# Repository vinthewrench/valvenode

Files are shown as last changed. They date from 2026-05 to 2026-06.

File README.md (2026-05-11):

# ValveNode

ValveNode is a wired field-bus irrigation valve-control system for my Raspberry Pi farm automation stack.

This project is a continuation of the work described in [Off-Grid Farm Automation with Raspberry Pi](https://www.vinthewrench.com/p/off-grid-farm-automation-raspberry-pi).

The irrigation side started with a Raspberry Pi, relay outputs, and conventional sprinkler valve wiring, described in [Raspberry Pi Internet of Things - part 2: Controlling the Irrigation valves](https://www.vinthewrench.com/p/raspberry-pi-internet-of-things-part-23c). That proved the basic idea: local software can control real irrigation hardware without a cloud service or proprietary controller. It also exposed the usual field problems: long wire runs, voltage drop, power loss, serviceability, and too many individual valve wires returning to one box.

I later experimented with more efficient solenoid drive hardware using a DRV103 in [Not Another Sprinkler Valve Article](https://www.vinthewrench.com/p/not-another-sprinkler-valve-article). That design gives a conventional valve a strong opening pulse and then reduces average power with PWM, which matters for long wire runs and battery-backed operation.

As the farm kept expanding, the wiring problem started to matter more than the valve-control problem. Every new irrigation zone meant another long wire run back to the controller, more trenching, more splices, more voltage drop, and more things to troubleshoot later. At that point, spending a few extra dollars per valve for latching solenoids was worth it if it let the field wiring become a simple 4-wire RS-485 network.

ValveNode takes the next step: instead of pulling every valve wire back to the controller, it moves small controller cards out into the field.

A Raspberry Pi talks to a Valve Master over I2C. The Valve Master starts a 4-wire RS-485 field cable carrying power and data. Valve Node cards sit along that cable, and each card drives a local latching irrigation solenoid with a short polarity-controlled pulse.

The goal is simple: irrigation control that is local, wired, understandable, repairable, and expandable.

## Overview

The project has two primary components:

- `valvenode-master`  
  ATmega88PB-based I2C-to-RS-485 master controller.
  
    <p align="center">
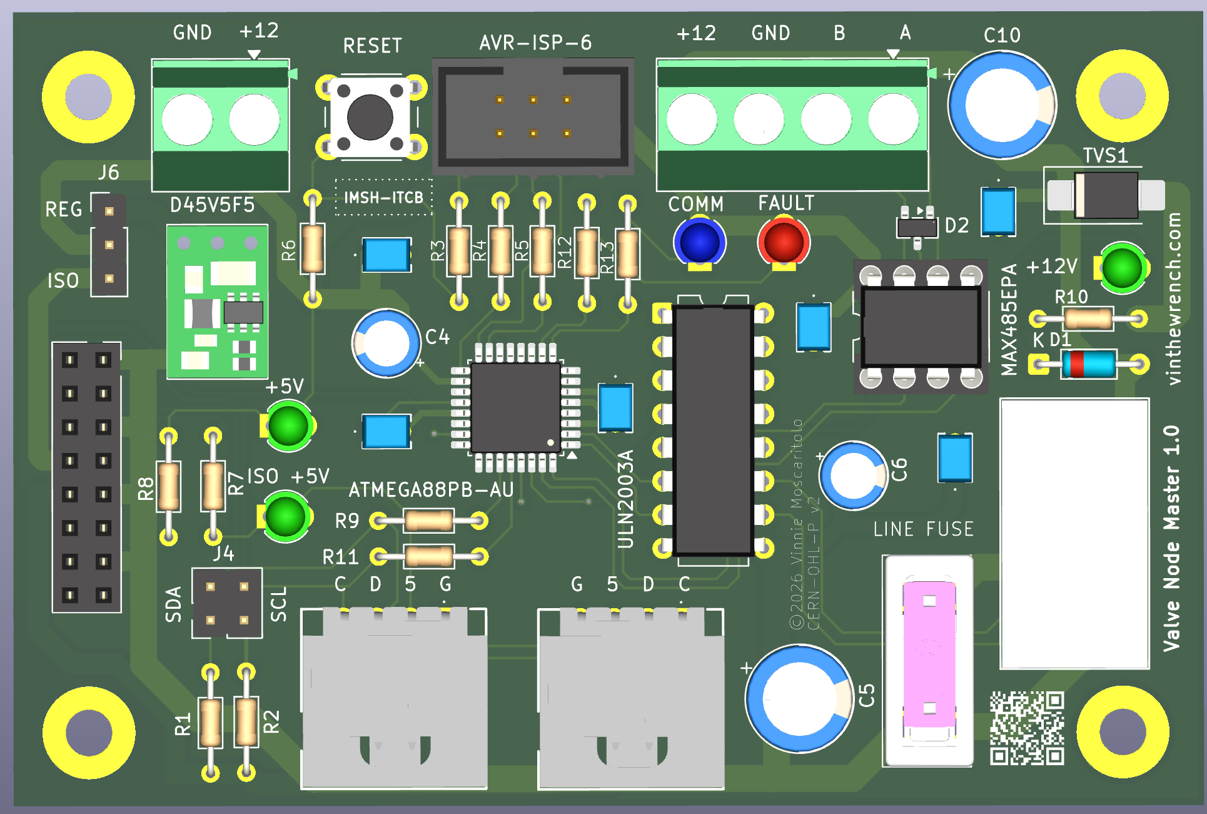
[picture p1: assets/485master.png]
valvenode-master
  
    </p>

- `valvenode-slave`  
  ATtiny4313-based RS-485 valve node for controlling latching irrigation valves.
  
<p align="center">
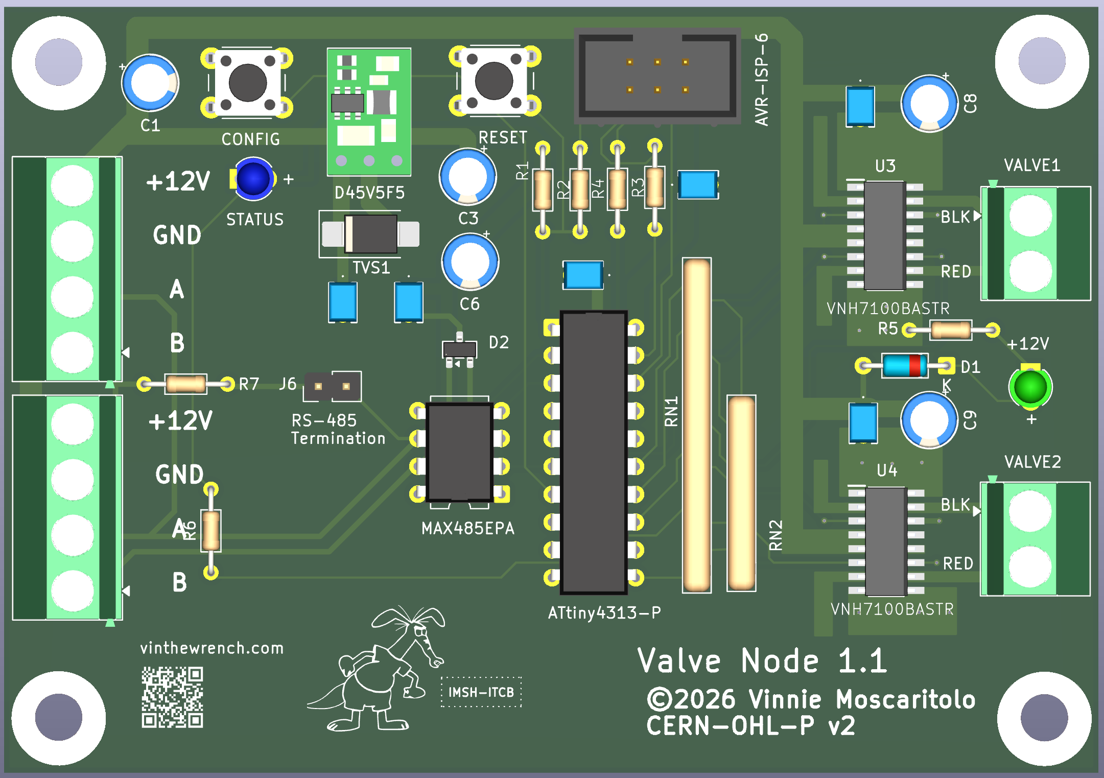
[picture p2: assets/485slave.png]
valvenode
  
</p>

The upstream controller talks to the Valve Master over I2C. The Valve Master controls field power and communicates with downstream Valve Nodes over RS-485.

<p align="center">
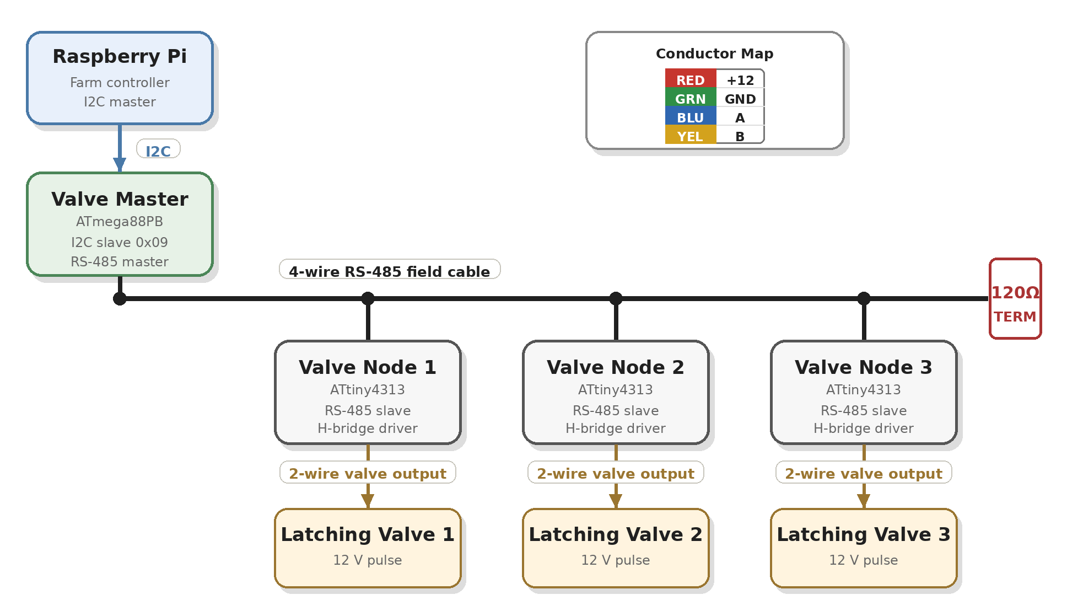
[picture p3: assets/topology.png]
ValveNode topology
  
</p>

### Latching Solenoids

ValveNode is designed around low-voltage DC latching irrigation solenoids. The initial supported solenoids are:

| Manufacturer | Part | Description | Notes |
|---|---:|---|---|
| Hunter | [458200](https://www.hunterirrigation.com/irrigation-product/solenoids/458200) | DC latching solenoid | Common Hunter solenoid for battery-operated and DC-latching valve control |
| Rain Bird | [K80920](https://store.rainbird.com/tbospsol-tbos-potted-latching-solenoid.html) / TBOSPSOL | 9 V DC potted latching solenoid | Fits many Rain Bird valve bodies, including DV, DVF, ASVF, PGA, PEB, PESB, GB, EFB-CP, BPE, and BPES series valves |

A latching solenoid is not powered continuously. The Valve Node drives it with a short polarity-controlled pulse through the H-bridge: one polarity opens the valve, the opposite polarity closes it, and then the output is turned off.

## Project Goals

- Wired field-bus control for irrigation valves
- No cloud dependency
- No wireless dependency
- Local 12 V field-power switching
- Half-duplex RS-485 node communication
- AVR-based firmware that can be understood, built, and serviced
- KiCad hardware source included
- Separate master firmware, simulator, Linux test tool, and node firmware

## Repository Layout

~~~text
valvenode/
├── valvenode-master/
│   ├── docs/
│   ├── firmware/
│   ├── hw/
│   │   └── 1.0/
│   ├── sim/
│   └── test/
└── valvenode-slave/
    ├── docs/
    ├── firmware/
    ├── hw/
    │   ├── 1.0/
    │   └── 1.1/
    └── test/
~~~

## Valve Master

Path:

~~~text
valvenode-master/
~~~

The Valve Master is the central controller for the valve-node network.

It performs these jobs:

- Accepts host commands over I2C
- Controls switched 12 V field-bus power
- Sends RS-485 commands to downstream valve nodes
- Receives valve-node replies
- Maintains node discovery state
- Reports status and command results to the host
- Provides local visual status indication
- Exposes AVR ISP programming access

Default I2C address:

~~~text
0x09
~~~

Address `0x08` is reserved for a separate power-control board, so `0x09` is used as the default Valve Master address.

### Valve Master Hardware

Path:

~~~text
valvenode-master/hw/1.0/
~~~

Important KiCad source files:

~~~text
valvenode-master.kicad_pro
valvenode-master.kicad_sch
valvenode-master.kicad_pcb
~~~

The master board uses:

- ATmega88PB-AU
- MAX485-style RS-485 transceiver
- Relay-switched 12 V field-bus output
- FAULT input
- COMM and FAULT indicators
- AVR ISP header
- I2C host-side interface

### Valve Master Firmware

Path:

~~~text
valvenode-master/firmware/
~~~

Files:

~~~text
makefile
valvenode_master.c
~~~

The firmware implements the production Valve Master behavior:

- I2C slave interface
- Register map
- Deferred command handling
- RS-485 transmit/receive control
- Field-bus power control
- Node discovery
- Valve-node command dispatch
- Result and reply registers
- Fault/status reporting

Directed RS-485 commands include timeout handling and retry behavior. A single missed node reply should not turn into an immediate hard failure on a slow irrigation field bus.

Build:

~~~bash
cd valvenode-master/firmware
make
~~~

### Valve Master Simulator

Path:

~~~text
valvenode-master/sim/
~~~

Files:

~~~text
makefile
valvenode_master_sim.c
~~~

The simulator models the master command/register behavior for bench testing without hardware.

Build:

~~~bash
cd valvenode-master/sim
make
~~~

### Valve Master Linux Test Tool

Path:

~~~text
valvenode-master/test/
~~~

Files:

~~~text
makefile
Doxyfile
src/
~~~

Source files:

~~~text
I2C.cpp
I2C.hpp
LogMgr.cpp
LogMgr.hpp
TimeStamp.cpp
TimeStamp.hpp
Valve_master.cpp
Valve_master.hpp
main.cpp
~~~

The test tool is a Linux-side C++ program used to talk to the Valve Master over `/dev/i2c-*`.

The main C++ class is:

~~~text
Valve_master
~~~

It wraps the Valve Master I2C register map and command model.

Typical responsibilities:

- Open the Linux I2C device
- Select the Valve Master I2C address
- Read and write registers
- Submit commands
- Wait for command completion
- Read command results
- Read reply registers
- Read discovered node map
- Query firmware versions
- Control field power
- Ping nodes
- Set valve/channel state

Build:

~~~bash
cd valvenode-master/test
make
~~~

Common `valve` commands:

~~~bash
./valve status
./valve power on
./valve power off
./valve who
./valve map
./valve ping 1
./valve set 1 1 on
./valve set 1 1 off
./valve channel 1 1 status
./valve version master
./valve version 1
./valve identify 1
./valve cancel
~~~

Provisioning commands:

~~~bash
./valve config
./valve assign 7
./valve move 7 8
~~~

### Hammer Test

Path:

~~~text
valvenode-master/test/hammer.sh
~~~

`hammer.sh` repeatedly exercises the full Valve Master path.

Test pattern:

~~~text
power on
ping nodes
initial status nodes
loop:
  set ON nodes
  status nodes
  set OFF nodes
  status nodes
final status nodes
power off
~~~

Example:

~~~bash
cd valvenode-master/test
./hammer.sh 25
NODES="1 3 4 5 6" CHANNEL=1 ./hammer.sh 500
~~~

Optional settings:

~~~bash
CHANNEL=2 ./hammer.sh 25
VERBOSE=1 ./hammer.sh 25
VALVE_BIN=./valve ./hammer.sh 25
NODES="1 3 4 5 6" ./hammer.sh 25
RETRY_ON_FAIL=1 ./hammer.sh 25
~~~

Recent bench result:

~~~text
500 loops
5 nodes tested: 1 3 4 5 6
channel 1
10,016 commands
0 failures
100% first-try pass rate
~~~

Generate local Doxygen docs:

~~~bash
cd valvenode-master/test
doxygen Doxyfile
open docs/html/index.html
~~~

## Valve Master I2C Register Model

The host talks to the master through a small register map.

Important registers include:

~~~text
REG_COMMAND
REG_STATUS
REG_ARG0
REG_ARG1
REG_ARG2
REG_RESULT
REG_POWER_STATE
REG_NODE_COUNT
REG_REPLY_NODE
REG_REPLY_CMD
REG_REPLY_ARG0
REG_REPLY_ARG1
REG_VERSION_HI
REG_VERSION_LO
REG_NODE_MAP
~~~

Important command values include:

~~~text
CMD_POWER_ON
CMD_POWER_OFF
CMD_WHO
CMD_PING
CMD_SET_CHANNEL
CMD_GET_CHANNEL_STATUS
CMD_GET_NODE_VERSION
CMD_IDENTIFY
CMD_CANCEL
CMD_CONFIG
CMD_ASSIGN
CMD_CLEAR_ERROR
CMD_SET_ERROR
CMD_CLOSE_ALL
~~~

Important status bits include:

~~~text
STATUS_BUSY
STATUS_ERROR
STATUS_POWER_ON
~~~

Important result values include:

~~~text
RESULT_OK
RESULT_BAD_COMMAND
RESULT_BAD_NODE
RESULT_BAD_CHANNEL
RESULT_NODE_NOT_FOUND
RESULT_UNSUPPORTED_CHANNEL
RESULT_CONFIG_REQUIRED
RESULT_ADDRESS_IN_USE
RESULT_BUSY
RESULT_RS485_TIMEOUT
RESULT_RS485_BAD_CHECKSUM
RESULT_RS485_BAD_REPLY
RESULT_POWER_OFF
~~~

## Valve Node

Path:

~~~text
valvenode-slave/
~~~

The Valve Node is the remote field device. It receives RS-485 commands and drives a 12 V latching irrigation valve.

Core functions:

- Receive framed RS-485 commands
- Check destination address
- Respond to discovery and status commands
- Drive a latching valve using a polarity-controlled pulse
- Turn the H-bridge fully off after each pulse
- Report current logical valve state

### Valve Node Hardware

Paths:

~~~text
valvenode-slave/hw/1.0/
valvenode-slave/hw/1.1/
~~~

Important KiCad source files:

~~~text
valvenode.kicad_pro
valvenode.kicad_sch
valvenode.kicad_pcb
~~~

The `1.1` hardware directory is the newer active revision.

The node hardware uses:

- ATtiny4313
- 5 V RS-485 transceiver
- VNH7100BAS / VNH7100BASTR H-bridge
- 12 V latching irrigation valve output
- 12 V field-bus input
- Local 5 V regulator
- Optional status LED

Basic field connection:

~~~text
+12 V
GND
RS-485 A
RS-485 B
~~~

The design is intended for direct-burial irrigation cable.

Recommended cable:

- 18/4 acceptable for shorter runs
- 16/4 preferred for longer runs or higher node counts

### Valve Node Power Architecture

The node receives 12 V from the field cable.

Power paths:

- 12 V directly feeds the valve driver supply
- 12 V feeds a local 5 V regulator
- 5 V powers the ATtiny4313 and RS-485 transceiver

Recommended protection and stability parts include:

- Bidirectional TVS across the 12 V input
- Bulk capacitance near the H-bridge supply
- 0.1 uF local decoupling at MCU and transceiver
- Additional 5 V bulk capacitance near the MCU
- Reverse-polarity protection where practical

For master-side field power switching, allow roughly 250 to 300 ms after switching on the 12 V field bus before sending node commands.

### Valve Node Firmware

Path:

~~~text
valvenode-slave/firmware/
~~~

Files:

~~~text
makefile
valvenode.c
valvenode_example_commands.txt
~~~

The firmware target is the ATtiny4313.

Firmware responsibilities:

- UART receive
- RS-485 command parsing
- Address matching
- Optional checksum checking
- Valve open pulse
- Valve close pulse
- Status reporting
- Ping reply
- WHO discovery reply
- Safe H-bridge shutdown after each pulse

Build:

~~~bash
cd valvenode-slave/firmware
make
~~~

### Valve Node Test Tool

Path:

~~~text
valvenode-slave/test/
~~~

Files:

~~~text
makefile
src/main.cpp
~~~

The `vnode` utility is used for direct bench testing of valve nodes over a serial port. It assumes the computer is connected to the RS-485 bus through a USB-to-RS-485 adapter.

This bypasses the Valve Master and talks directly to the nodes.

Build:

~~~bash
cd valvenode-slave/test
make
~~~

Example:

~~~bash
./vnode -d /dev/ttyUSB0 who
./vnode -d /dev/ttyUSB0 ping 1
./vnode -d /dev/ttyUSB0 open 1 1
./vnode -d /dev/ttyUSB0 close 1 1
~~~

Typical output:

~~~text
$ ./vnode -d /dev/ttyUSB0 who
device: /dev/ttyUSB0
baud:   9600
tx: :FFW\r
rx: :01WB8  [checksum ok] node=1 WHO
rx: :02WB9  [checksum ok] node=2 WHO
~~~

`vnode` can also be used to configure a fresh node, assign its address, and verify that it answers before it goes into the field.

## RS-485 Valve Node Protocol

The Valve Master and Valve Nodes communicate over a half-duplex RS-485 bus.

The node protocol is command/response. The master sends a framed command. A node replies only when addressed or when participating in a controlled discovery response.

Typical commands:

~~~text
PING
STATUS
OPEN
CLOSE
WHO
IDENTIFY
CONFIG
ASSIGN
VERSION
~~~

Typical behavior:

- `PING` confirms node presence
- `STATUS` reports logical valve/channel state
- `OPEN` sends the open-polarity valve pulse
- `CLOSE` sends the close-polarity valve pulse
- `WHO` is used for node discovery
- `IDENTIFY` asks a node to identify itself
- `CONFIG` enters configuration behavior
- `ASSIGN` sets or changes a node address
- `VERSION` reports firmware version

Broadcast state-changing commands should be avoided unless explicitly implemented and safe.

## Useful Linux I2C Commands

List I2C buses:

~~~bash
i2cdetect -l
ls -l /dev/i2c-*
~~~

Scan I2C bus 1:

~~~bash
i2cdetect -y 1
~~~

Look for the Valve Master at address `0x09`.

Check user permissions for I2C:

~~~bash
groups
ls -l /dev/i2c-*
~~~

If needed, add the user to the `i2c` group on Linux:

~~~bash
sudo usermod -aG i2c $USER
~~~

Then log out and back in.

## Development Notes

- The Valve Master default I2C address is `0x09`.
- The Valve Master controls field-bus 12 V power.
- The Valve Nodes are not autonomous irrigation controllers.
- Valve Nodes execute direct command/response behavior.
- Latching valves must be driven with short pulses, not continuous power.
- H-bridge outputs must be turned off after each pulse.
- RS-485 bus direction control must be handled carefully to avoid bus contention.
- Field wiring should assume noise, voltage drop, wet boxes, lightning exposure, and field-service abuse.

## Current Project Status

The repository currently contains:

- Valve Master hardware design
- Valve Master firmware
- Valve Master simulator
- Valve Master Linux I2C test tool: `valve`
- Valve Master hammer test: `hammer.sh`
- Valve Node hardware revisions
- Valve Node firmware
- Valve Node direct RS-485 test tool: `vnode`
- Protocol and design documentation

Current bench status:

- Valve Master can switch field power
- Valve Master can communicate with multiple valve nodes over RS-485
- Valve nodes respond to discovery, ping, set, and status commands
- `hammer.sh` has completed a 500-loop, 10,016-command bench test across five nodes with zero failures

Remaining validation:

- Confirm final latching-solenoid open/close polarity with real valve bodies
- Test final assembled boards in outdoor enclosures
- Validate longer real field-cable runs
- Continue field reliability testing before treating the system as deployed infrastructure

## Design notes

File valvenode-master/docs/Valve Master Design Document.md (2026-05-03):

# Valve Master Design Document (v0.3)

**Date:** 2026-04-22

## 1. Purpose and Scope

The Valve Master is the controller for the RS-485 valve network. It powers the field bus, sends commands to valve-node slaves, receives replies, monitors a fault input, and provides local visual status.

This document covers the current master board as drawn in the uploaded schematic and BOM.

Design goals:
- Offline operation
- Deterministic command/response behavior
- Simple firmware and easy field debugging
- RS-485 half-duplex bus control
- Master-side switched 12 V field power
- Separate COMM and FAULT indicators
- Clean service access for reset and AVR-ISP
- Dual-use assembly option depending on host system

## 2. Source of Truth

This document is based on:
- Uploaded master schematic
- Uploaded BOM
- Locked ATmega88PB-AU pin assignments from this conversation
- Locked design rule that the master is not terminated
- User-defined dual-use assembly mode described in this conversation
- GardenIrrigation repository reference for the garden-system mode  [oai_citation:0‡GitHub](https://github.com/vinthewrench/GardenIrrigation)

## 3. High-Level Function

The master board performs these functions:

1. Accept raw +12 V input power when used in standalone NodeLync mode.
2. Generate local +5 V logic power when the onboard regulator is used.
3. Switch field +12 V to the downstream valve-node network through a relay.
4. Drive an RS-485 half-duplex network through a MAX485.
5. Monitor a FAULT input.
6. Indicate power, communication activity, fault state, and switched 12 V state with LEDs.
7. Expose AVR-ISP programming and reset access.
8. Provide nodeLync / isolated-side headers and I2C signals.
9. Support two distinct assembly/use modes.

## 4. Two Supported Assembly / Use Modes

This board can be built and used in two different ways.

### Mode A: Standalone NodeLync wiring mode

In this mode the board is wired using the NodeLync IN and OUT connectors.

Requirements:
- Raw +12 V supply is provided to the board.
- The onboard regulator **D45V5F5** is populated.
- The NodeLync connectors are populated.
- Jumper **J6 POWER_SELECT** is set to **REG**.

In this mode:
- the board makes its own local +5 V from the onboard regulator
- NodeLync IN and OUT are used as the system interconnect
- this is the self-powered standalone master configuration

### Mode B: GardenIrrigation system mode

In this mode the board is plugged into the user's GardenIrrigation system as defined by the referenced repository. The repository is the hardware for the garden irrigation project and includes the garden PCB and DRV103 plugin board context.  [oai_citation:1‡GitHub](https://github.com/vinthewrench/GardenIrrigation)

Requirements:
- Jumper **J6 POWER_SELECT** is set to **ISO**
- NodeLync IN and OUT connectors are **not populated**
- The onboard regulator **D45V5F5** is **not populated**

In this mode:
- the board is powered from the external GardenIrrigation system side
- the isolated / external +5 V path is used instead of the local regulator
- NodeLync connectors are omitted from assembly

## 5. Major Components

### Core Logic
- **U2**: ATMEGA88PB-AU

### RS-485 Interface
- **U4**: MAX485EPA
- **D2**: SM712_SOT23, RS-485 line protection on A/B

### Power
- **J1**: raw +12 V power input
- **U1**: D45V5F5, 5 V regulator
- **TVS1**: P6SMB18A, 12 V line clamp
- **J6**: POWER_SELECT header, selects REG or ISO source

### Relay / Field Power Switching
- **U3**: ULN2003A
- **K1**: DSP1-L2-DC12V relay
- **F1**: Keystone 3568 fuse holder
- **Output**: +12 SWITCHED

### User / Service Interface
- **SW1**: reset switch
- **J2**: AVR-ISP-6 programming header

### Indicators
- **LED1**: ISO +5 V indicator, green
- **LED2**: +5 V indicator, green
- **LED3**: +12 V switched indicator, green
- **LED4**: COMM indicator, blue
- **LED5**: FAULT indicator, red

## 6. Power Architecture

### Inputs
- Raw supply enters on **J1** as **+12V** and **GND1** when used in standalone mode.

### Protection
- **TVS1 = P6SMB18A** clamps the 12 V input line.
- **D2 = SM712** protects the RS-485 A/B lines.

### Regulation / Source Selection
The board supports two possible +5 V sourcing paths.

#### REG position
- selected when onboard regulator is used
- requires **U1 = D45V5F5** to be populated
- used in standalone NodeLync mode

#### ISO position
- selected when +5 V is supplied externally by the host system
- used in GardenIrrigation system mode
- in this mode **U1** is not populated

### Switched Field Power
- Relay **K1** switches field power and produces **+12 SWITCHED**
- Relay is driven by **ULN2003A**
- Fuse holder **F1** is in the switched power path

## 7. Board-Level Signal Assignments

## 7.1 Locked MCU Pin Assignment

| AVR Pin | Function | Direction | Notes |
|---|---|---|---|
| PB3 | MOSI | I/O | SPI / AVR-ISP |
| PB4 | MISO | I/O | SPI / AVR-ISP |
| PB5 | SCK | I/O | SPI / AVR-ISP |
| PC0 | FAULT | Input | Fault sense input |
| PC4 | ISO SDA | I/O | I2C SDA through R9 |
| PC5 | ISO SCL | I/O | I2C SCL through R11 |
| PD0 | 485RX | Input | UART RX from MAX485 RO |
| PD1 | 485TX | Output | UART TX to MAX485 DI |
| PD2 | 485DE | Output | MAX485 RE/DE control |
| PD3 | RELAY SET / drive out | Output | ULN2003A input |
| PD4 | RELAY RESET / drive out | Output | ULN2003A input |
| PD5 | BLUE LED COMM | Output | Communication activity LED |
| PD6 | RED LED FAULT | Output | Fault LED |
| PC6 | RESET | Input | Reset pull-up and reset switch |

## 8. Connector Table

| Ref | Description | Function |
|---|---|---|
| J1 | 2-pin 5.08 mm terminal | Raw +12 V power input |
| J2 | AVR-ISP-6 | Programming header |
| J3 | nodeLync OUT, 3-pin | NodeLync output, populate only in standalone mode |
| J5 | nodeLync IN, 3-pin | NodeLync input, populate only in standalone mode |
| J6 | 1x03 header | POWER_SELECT, REG or ISO |
| J7 | 2x08 socket | ISO / bus-side support signals |
| J8 | 4-pin 5.08 mm terminal | RS-485 and field power out: B, A, GND1, +12V |

## 9. RS-485 Interface Details

### Transceiver
- **MAX485EPA**

### Connections
- `RO` -> `485RX` -> U2 PD0
- `DI` <- `485TX` <- U2 PD1
- `RE` and `DE` tied together -> `485DE` -> U2 PD2
- `A` -> `485_A`
- `B` -> `485_B`

### Bus Connector J8
| J8 Pin | Signal |
|---|---|
| 1 | B |
| 2 | A |
| 3 | GND1 |
| 4 | +12V |

### Protection
- **SM712** is placed on the A/B pair

### Termination Policy
The master does not include RS-485 termination.

Termination is provided only at selected remote slave nodes that serve as the two physical end points of the installed network.

## 10. I2C / External Support Signals

The schematic shows support signals brought through J7 and through series resistors into the MCU:

- **ISO SDA** through **R9 = 220 Ω** to **PC4**
- **ISO SCL** through **R11 = 220 Ω** to **PC5**
- **FAULT** brought to **PC0**
- **ISO +5V**
- **+12V**
- **GND1**

**I2C address is 0x09**

## 11. Reset and Programming

### Reset
- **R6 = 10K** pull-up on RESET
- **SW1** reset switch to ground

### AVR-ISP
- **J2** AVR-ISP-6
- Series resistors on programming-related lines:
  - **R3 = 470 Ω**
  - **R4 = 470 Ω**
  - **R5 = 470 Ω**

## 12. LED Functions

### LED1
- Green
- ISO +5 V present

### LED2
- Green
- Local +5 V present

### LED3
- Green
- +12 V switched present

### LED4
- Blue
- COMM activity

### LED5
- Red
- FAULT indication

## 13. Assembly Variants

## 13.1 Standalone NodeLync build
Populate:
- J3
- J5
- U1
- associated regulator support parts
- J6 set to REG

Requires:
- local +12 V input

## 13.2 GardenIrrigation build
Do not populate:
- J3
- J5
- U1

Set:
- J6 to ISO

This build relies on the external GardenIrrigation system for the selected supply path and interface context. The referenced repository describes that garden hardware project.  [oai_citation:2‡GitHub](https://github.com/vinthewrench/GardenIrrigation)

## 14. Firmware Behavior Assumptions

The master firmware should follow strict request/reply rules:

- one request
- one reply or timeout
- then next request

Do not pipeline commands.

Suggested responsibilities:
- drive `485DE` only during transmit
- wait for reply or timeout before sending next command
- validate reply structure and checksum
- control relay drive outputs safely
- monitor `FAULT`
- flash COMM LED on send and/or receive
- assert FAULT LED when fault is present

## Master Functional Role

The master board acts as an I2C-controlled RS-485 valve network controller.

It is commanded by an upstream host over I2C. The host does not talk directly to valve slaves.

The master performs these operations on behalf of the host:

- power the RS-485 valve bus on through the relay
- wait for field-side power stabilization
- transmit RS-485 valve-node commands
- wait for reply or timeout
- optionally query node status
- power the RS-485 bus back off after command completion

This architecture is intended for latching-solenoid valve nodes, where continuous field power is not required.

## Planned I2C Command Model

The I2C interface will be used to command the master to perform valve-network actions.

Planned command categories:
- valve ON / OPEN
- valve OFF / CLOSE
- status request
- slave address configuration / enrollment
- optional discovery / identify operations

The exact I2C register map and command encoding are still to be defined.

## 15. Open Items / Review Notes

1. Confirm exact relay semantics of PD3 and PD4 in final firmware.
2. Confirm fuse sizing for the switched 12 V field feed.
3. Confirm external bus bias location, since the master is not terminated.
4. Mechanical review still needed for final enclosure fit and connector access.
5. Final assembly documentation should explicitly separate the standalone REG build from the GardenIrrigation ISO build.

## 16. Summary

The master board supports two valid build modes:

- a standalone NodeLync-based self-powered build using the onboard regulator with J6 set to REG
- a GardenIrrigation-hosted build using the external system path with J6 set to ISO, with NodeLync connectors and U1 not populated

In both cases the board remains the RS-485 command master, provides relay-switched 12 V field power, uses MAX485 for the bus, uses SM712 for A/B protection, and does not provide RS-485 termination on the master.

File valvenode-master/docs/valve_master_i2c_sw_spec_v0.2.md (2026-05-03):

# Valve Master I2C Software Specification

Version: 0.2  
Target board: Valve Master  
MCU: ATmega88PB-AU  
I2C role: slave device  
Default I2C address: 0x09

## 1. Purpose

The Valve Master board provides an I2C interface between the host controller and an RS485 valve-node network.

The Valve Master is responsible for:

~~~text
receiving simple I2C commands
controlling the RS485 transceiver
sending valve commands to slave valve nodes
reporting command status and result
optionally scanning the RS485 bus for responding nodes
controlling relay power to the slave valve-node bus
~~~

The host/client driver is responsible for higher-level policy:

~~~text
power sequencing
wake delay after slave power-on
command queueing
relay anti-chatter timing
completion callbacks
configuration of expected valve nodes
~~~

The firmware does not manage command queues or wake delays.

## 2. I2C Address

The Valve Master uses this default 7-bit I2C address:

~~~c
#define VM_I2C_ADDR  0x09
~~~

Address 0x08 is reserved for the existing power-control board.

Reserved future Valve Master alternate addresses:

~~~text
0x0A
0x0B
0x0C
~~~

## 3. I2C Transaction Model

The Valve Master uses a register-style I2C interface.

Typical write:

~~~text
START
I2C_ADDR + WRITE
REGISTER
DATA...
STOP
~~~

Typical read:

~~~text
START
I2C_ADDR + WRITE
REGISTER
REPEATED START
I2C_ADDR + READ
DATA...
STOP
~~~

Long operations are asynchronous.

An I2C write to COMMAND means:

~~~text
command accepted or rejected by the Valve Master
~~~

It does not mean:

~~~text
the RS485 slave completed the operation
~~~

For commands involving RS485, the client must:

~~~text
write command
poll STATUS until BUSY clears
read LAST_RESULT
~~~

## 4. Register Map

### 4.1 Core Registers

~~~text
0x00  COMMAND
0x01  STATUS
0x02  CURRENT_NODE
0x03  NODE_COUNT
0x04  ARG0
0x05  ARG1
0x06  POWER_STATE
0x07  LAST_RESULT
~~~

### 4.2 Master Version Registers

~~~text
0x08  MASTER_VERSION_HI
0x09  MASTER_VERSION_LO
0x0A  MASTER_PROTOCOL
~~~

The master firmware version is stored as a packed 16-bit BCD value, high byte first.

Example:

~~~text
0x0100 = 1.00
0x0215 = 2.15
~~~

### 4.3 Last Queried Node Info Registers

~~~text
0x10  NODE_INFO_ID
0x11  NODE_VERSION_HI
0x12  NODE_VERSION_LO
0x13  NODE_PROTOCOL
0x14  NODE_VALVE_COUNT
0x15  NODE_BOARD_TYPE
~~~

These registers contain the cached result of the most recent GET_NODE_INFO command.

### 4.4 Node Bitmap

~~~text
0x20-0x3F  NODE_MAP[32]
~~~

This is a 32-byte bitmap showing which RS485 node addresses responded to the most recent WHO_SCAN.

### 4.5 Reserved

~~~text
0x0B-0x0F  reserved
0x16-0x1F  reserved
0x40-0xFF  reserved for future use
~~~

## 5. Register Details

### 5.1 COMMAND, 0x00

Write-only command register.

Writing a command value starts the requested operation.

~~~c
#define VM_REG_COMMAND  0x00
~~~

Supported commands:

~~~c
#define VM_CMD_NONE       0x00
#define VM_CMD_WHO_SCAN   0x01
#define VM_CMD_SET_VALVE  0x02
#define VM_CMD_POWER_ON   0x03
#define VM_CMD_POWER_OFF  0x04
#define VM_CMD_GET_NODE_INFO  0x05
~~~

### 5.2 STATUS, 0x01

Read-only status register.

~~~c
#define VM_REG_STATUS  0x01
~~~

Status bits:

~~~c
#define VM_STATUS_READY      0x01
#define VM_STATUS_BUSY       0x02
#define VM_STATUS_MAP_VALID  0x04
#define VM_STATUS_ERROR      0x08
#define VM_STATUS_POWER_ON   0x10
~~~

| Bit | Name | Meaning |
|---:|---|---|
| 0x01 | READY | Firmware initialized |
| 0x02 | BUSY | Command in progress |
| 0x04 | MAP_VALID | NODE_MAP contains valid scan data |
| 0x08 | ERROR | Last completed command failed |
| 0x10 | POWER_ON | Slave-node power relay is on |

Normal boot state:

~~~text
READY = 1
BUSY = 0
MAP_VALID = 0
ERROR = 0
POWER_ON = 0
~~~

### 5.3 CURRENT_NODE, 0x02

Read-only.

~~~c
#define VM_REG_CURRENT_NODE  0x02
~~~

During WHO_SCAN, this contains the RS485 node address currently being tested.

During SET_VALVE, this contains the target node address.

When idle, this should be:

~~~text
0x00
~~~

### 5.4 NODE_COUNT, 0x03

Read-only.

~~~c
#define VM_REG_NODE_COUNT  0x03
~~~

Number of nodes discovered during the most recent WHO_SCAN.

Valid range:

~~~text
0-254
~~~

### 5.5 ARG0, 0x04

Read/write argument register.

~~~c
#define VM_REG_ARG0  0x04
~~~

For SET_VALVE:

~~~text
ARG0 = RS485 node ID
~~~

Valid node IDs:

~~~text
1-254
~~~

Reserved:

~~~text
0   invalid / master / unused
255 broadcast / reserved
~~~

### 5.6 ARG1, 0x05

Read/write argument register.

~~~c
#define VM_REG_ARG1  0x05
~~~

For SET_VALVE, this is the packed valve/state byte.

~~~text
bit 7     state
          0 = OFF / CLOSE
          1 = ON / OPEN

bits 2-0  valve index
          0 = valve 1
          1 = valve 2
          ...
          7 = valve 8

bits 6-3  reserved, must be 0
~~~

Definitions:

~~~c
#define VM_VALVE_STATE_BIT        0x80
#define VM_VALVE_INDEX_MASK       0x07
#define VM_VALVE_RESERVED_MASK    0x78
~~~

| Valve | State | ARG1 |
|---:|---|---:|
| 1 | OFF | 0x00 |
| 1 | ON | 0x80 |
| 2 | OFF | 0x01 |
| 2 | ON | 0x81 |
| 8 | OFF | 0x07 |
| 8 | ON | 0x87 |

### 5.7 POWER_STATE, 0x06

Read-only.

~~~c
#define VM_REG_POWER_STATE  0x06
~~~

Values:

~~~c
#define VM_POWER_OFF  0x00
#define VM_POWER_ON   0x01
~~~

This mirrors the relay output state.

### 5.8 LAST_RESULT, 0x07

Read-only.

~~~c
#define VM_REG_LAST_RESULT  0x07
~~~

Result of the most recently completed or rejected command.

~~~c
#define VM_RESULT_OK              0x00
#define VM_RESULT_BUSY            0x01
#define VM_RESULT_BAD_NODE        0x02
#define VM_RESULT_BAD_ARGUMENT    0x03
#define VM_RESULT_NODE_NOT_FOUND  0x04
#define VM_RESULT_RS485_TIMEOUT   0x05
#define VM_RESULT_RS485_ERROR     0x06
#define VM_RESULT_POWER_OFF       0x07
#define VM_RESULT_BAD_COMMAND     0x08
~~~

### 5.9 MASTER_VERSION_HI / MASTER_VERSION_LO, 0x08-0x09

Read-only.

~~~c
#define VM_REG_MASTER_VERSION_HI  0x08
#define VM_REG_MASTER_VERSION_LO  0x09
~~~

The Valve Master firmware version as a packed 16-bit BCD value, high byte first.

~~~text
0x0100 = 1.00
0x0215 = 2.15
~~~

### 5.10 MASTER_PROTOCOL, 0x0A

Read-only.

~~~c
#define VM_REG_MASTER_PROTOCOL  0x0A
~~~

Protocol version implemented by the Valve Master firmware.

### 5.11 NODE_INFO_ID, 0x10

Read-only.

~~~c
#define VM_REG_NODE_INFO_ID  0x10
~~~

RS485 node ID for the most recently cached node-info response. This register is valid only after GET_NODE_INFO completes with VM_RESULT_OK.

### 5.12 NODE_VERSION_HI / NODE_VERSION_LO, 0x11-0x12

Read-only.

~~~c
#define VM_REG_NODE_VERSION_HI  0x11
#define VM_REG_NODE_VERSION_LO  0x12
~~~

Firmware version of the most recently queried slave node as a packed 16-bit BCD value, high byte first.

### 5.13 NODE_PROTOCOL, 0x13

Read-only.

~~~c
#define VM_REG_NODE_PROTOCOL  0x13
~~~

RS485 protocol version reported by the most recently queried slave node.

### 5.14 NODE_VALVE_COUNT, 0x14

Read-only.

~~~c
#define VM_REG_NODE_VALVE_COUNT  0x14
~~~

Number of valve channels reported by the most recently queried slave node. Present dual-valve boards should report 2. Future boards may report up to 8.

### 5.15 NODE_BOARD_TYPE, 0x15

Read-only.

~~~c
#define VM_REG_NODE_BOARD_TYPE  0x15
~~~

Board-type identifier reported by the most recently queried slave node. Exact board-type values are reserved for the slave-node protocol definition.

## 6. Node Bitmap

The node bitmap is located at:

~~~c
#define VM_REG_NODE_MAP  0x20
~~~

Register range:

~~~text
0x20-0x3F
~~~

Length:

~~~text
32 bytes
~~~

The bitmap represents RS485 node IDs 1-254.

Mapping:

~~~c
byte_index = node_id >> 3;
bit_index  = node_id & 0x07;
~~~

Node examples:

~~~text
node 1   -> NODE_MAP[0], bit 1
node 2   -> NODE_MAP[0], bit 2
node 7   -> NODE_MAP[0], bit 7
node 8   -> NODE_MAP[1], bit 0
node 17  -> NODE_MAP[2], bit 1
node 254 -> NODE_MAP[31], bit 6
~~~

Node 0 is unused. Node 255 is reserved.

To read the full map:

~~~bash
i2ctransfer -y 1 w1@0x09 0x20 r32
~~~

## 7. Commands

### 7.1 VM_CMD_WHO_SCAN

~~~c
#define VM_CMD_WHO_SCAN  0x01
~~~

Purpose:

~~~text
Scan RS485 node addresses 1-254 and record which nodes respond.
~~~

Arguments:

~~~text
none
~~~

Behavior:

~~~text
1. If BUSY is already set:
     reject command
     LAST_RESULT = VM_RESULT_BUSY
     ERROR = 1

2. Otherwise:
     clear NODE_MAP
     NODE_COUNT = 0
     MAP_VALID = 0
     ERROR = 0
     BUSY = 1

3. For node addresses 1-254:
     CURRENT_NODE = node
     send RS485 WHO request
     wait for valid reply
     if reply valid:
         set node bit in NODE_MAP
         increment NODE_COUNT

4. When scan completes:
     CURRENT_NODE = 0
     BUSY = 0
     MAP_VALID = 1
     LAST_RESULT = VM_RESULT_OK
~~~

The firmware does not automatically power on the slave-node bus before WHO_SCAN.

If the client wants to scan powered nodes, it must do:

~~~text
POWER_ON
wait client-defined wake delay
WHO_SCAN
poll BUSY
read NODE_MAP
~~~

### 7.2 VM_CMD_SET_VALVE

~~~c
#define VM_CMD_SET_VALVE  0x02
~~~

Purpose:

~~~text
Send an ON/OFF command to one valve on one RS485 valve-node board.
~~~

Arguments:

~~~text
ARG0 = node ID, 1-254
ARG1 = packed valve/state byte
~~~

Packed ARG1:

~~~text
bit 7     state, 0=OFF, 1=ON
bits 2-0  valve index, 0-7
bits 6-3  reserved, must be 0
~~~

Behavior:

~~~text
1. If BUSY is already set:
     reject command
     LAST_RESULT = VM_RESULT_BUSY
     ERROR = 1

2. Validate ARG0:
     valid node ID is 1-254
     otherwise LAST_RESULT = VM_RESULT_BAD_NODE

3. Validate ARG1:
     bits 6-3 must be 0
     otherwise LAST_RESULT = VM_RESULT_BAD_ARGUMENT

4. Check power:
     if POWER_ON is not set:
         LAST_RESULT = VM_RESULT_POWER_OFF
         ERROR = 1
         do not send RS485 command

5. If valid:
     BUSY = 1
     ERROR = 0
     CURRENT_NODE = ARG0

6. Send RS485 SET_VALVE command.

7. Wait for valid slave reply.

8. On success:
     LAST_RESULT = VM_RESULT_OK

9. On timeout:
     LAST_RESULT = VM_RESULT_RS485_TIMEOUT
     ERROR = 1

10. On malformed/error reply:
     LAST_RESULT = VM_RESULT_RS485_ERROR
     ERROR = 1

11. Clear:
     CURRENT_NODE = 0
     BUSY = 0
~~~

The firmware does not perform slave wake delay.

The client must do:

~~~text
POWER_ON
wait wake delay
SET_VALVE
poll BUSY
read LAST_RESULT
POWER_OFF when appropriate
~~~

### 7.3 VM_CMD_POWER_ON

~~~c
#define VM_CMD_POWER_ON  0x03
~~~

Purpose:

~~~text
Turn on relay power to slave valve-node boards.
~~~

Arguments:

~~~text
none
~~~

Behavior:

~~~text
1. Turn relay on.
2. POWER_STATE = VM_POWER_ON.
3. STATUS_POWER_ON = 1.
4. LAST_RESULT = VM_RESULT_OK.
~~~

The firmware does not wait for slaves to boot.

Wake delay is a client-driver responsibility.

### 7.4 VM_CMD_POWER_OFF

~~~c
#define VM_CMD_POWER_OFF  0x04
#define VM_CMD_GET_NODE_INFO  0x05
~~~

Purpose:

~~~text
Turn off relay power to slave valve-node boards.
~~~

Arguments:

~~~text
none
~~~

Behavior:

~~~text
1. Turn relay off.
2. POWER_STATE = VM_POWER_OFF.
3. STATUS_POWER_ON = 0.
4. MAP_VALID = 0.
5. LAST_RESULT = VM_RESULT_OK.
~~~

MAP_VALID is cleared because the discovered map is stale once slave-node power is removed.

### 7.5 VM_CMD_GET_NODE_INFO

~~~c
#define VM_CMD_GET_NODE_INFO  0x05
~~~

Purpose:

~~~text
Query one RS485 slave node and cache its version/capability information in the NODE_INFO registers.
~~~

Arguments:

~~~text
ARG0 = node ID, 1-254
~~~

Behavior:

~~~text
1. If BUSY is already set:
     reject command
     LAST_RESULT = VM_RESULT_BUSY
     ERROR = 1

2. Validate ARG0:
     valid node ID is 1-254
     otherwise LAST_RESULT = VM_RESULT_BAD_NODE

3. Check power:
     if POWER_ON is not set:
         LAST_RESULT = VM_RESULT_POWER_OFF
         ERROR = 1
         do not send RS485 command

4. If valid:
     BUSY = 1
     ERROR = 0
     CURRENT_NODE = ARG0

5. Send RS485 GET_NODE_INFO request.

6. Wait for valid slave reply.

7. On success:
     cache NODE_INFO_ID
     cache NODE_VERSION_HI / NODE_VERSION_LO
     cache NODE_PROTOCOL
     cache NODE_VALVE_COUNT
     cache NODE_BOARD_TYPE
     LAST_RESULT = VM_RESULT_OK

8. On timeout:
     LAST_RESULT = VM_RESULT_RS485_TIMEOUT
     ERROR = 1

9. On malformed/error reply:
     LAST_RESULT = VM_RESULT_RS485_ERROR
     ERROR = 1

10. Clear:
     CURRENT_NODE = 0
     BUSY = 0
~~~

The firmware does not perform slave wake delay. The client must explicitly power the slave bus and wait before issuing GET_NODE_INFO.

This command is intended for diagnostics, commissioning, and support for future slave boards with different valve counts or driver hardware.

## 8. Client Driver Flow

### 8.1 Normal SET_VALVE Flow

The client driver should perform:

~~~text
1. Queue valve request.
2. If slave power is off:
     send POWER_ON
     wait client-defined wake delay

3. Write ARG0 = node ID.
4. Write ARG1 = packed valve/state.
5. Write COMMAND = SET_VALVE.

6. Poll STATUS until BUSY clears.

7. Read LAST_RESULT.

8. Invoke completion callback.

9. If more queued valve requests exist:
     process next request.

10. If queue is idle:
     wait client-defined hold interval.
     send POWER_OFF.
~~~

Suggested client timing defaults:

~~~text
wake delay after POWER_ON:    500 ms
inter-command delay:          50-100 ms
idle power-off delay:         1-2 seconds
~~~

These are client policy values, not firmware constants.

### 8.2 Example: Node 7, Valve 2 ON

Valve 2 means valve index 1.

State ON means bit 7 set.

~~~text
ARG0 = 0x07
ARG1 = 0x81
COMMAND = 0x02
~~~

Linux command example:

~~~bash
i2cset -y 1 0x09 0x04 0x07
i2cset -y 1 0x09 0x05 0x81
i2cset -y 1 0x09 0x00 0x02
~~~

Poll status:

~~~bash
i2cget -y 1 0x09 0x01
~~~

When STATUS & 0x02 is zero, read result:

~~~bash
i2cget -y 1 0x09 0x07
~~~

Expected success:

~~~text
LAST_RESULT = 0x00
~~~

### 8.3 Example: Node 7, Valve 2 OFF

~~~text
ARG0 = 0x07
ARG1 = 0x01
COMMAND = 0x02
~~~

Linux:

~~~bash
i2cset -y 1 0x09 0x04 0x07
i2cset -y 1 0x09 0x05 0x01
i2cset -y 1 0x09 0x00 0x02
~~~

### 8.4 Example: Read Master Version

Read high and low bytes and combine them as a packed 16-bit BCD value.

~~~bash
i2cget -y 1 0x09 0x08
i2cget -y 1 0x09 0x09
~~~

Example result:

~~~text
MASTER_VERSION_HI = 0x01
MASTER_VERSION_LO = 0x00
version = 0x0100 = 1.00
~~~

### 8.5 Example: Read Node Info for Node 7

The client must power the slave bus and wait for node wakeup before issuing GET_NODE_INFO.

~~~bash
i2cset -y 1 0x09 0x00 0x03      # POWER_ON
sleep 1
i2cset -y 1 0x09 0x04 0x07      # ARG0 = node 7
i2cset -y 1 0x09 0x00 0x05      # GET_NODE_INFO
~~~

Poll status until BUSY clears:

~~~bash
i2cget -y 1 0x09 0x01
~~~

Then read LAST_RESULT:

~~~bash
i2cget -y 1 0x09 0x07
~~~

If LAST_RESULT is 0x00, read cached node information:

~~~bash
i2cget -y 1 0x09 0x10      # NODE_INFO_ID
i2cget -y 1 0x09 0x11      # NODE_VERSION_HI
i2cget -y 1 0x09 0x12      # NODE_VERSION_LO
i2cget -y 1 0x09 0x13      # NODE_PROTOCOL
i2cget -y 1 0x09 0x14      # NODE_VALVE_COUNT
i2cget -y 1 0x09 0x15      # NODE_BOARD_TYPE
~~~

## 9. Firmware Rules

### 9.1 I2C ISR Rule

The I2C interrupt handler must not perform RS485 work.

It may:

~~~text
store written register values
capture COMMAND
set command-pending flag
return quickly
~~~

The main loop performs:

~~~text
RS485 transmit
RS485 receive wait
timeouts
WHO scan
SET_VALVE transaction
~~~

### 9.2 Busy Rule

If a command is received while BUSY is set:

~~~text
reject command
LAST_RESULT = VM_RESULT_BUSY
ERROR = 1
~~~

No command queue is implemented in firmware.

The only exception may be added later for an ABORT command, but no abort command exists in v0.1.

### 9.3 Power Rule

SET_VALVE does not turn power on.

If field power is off:

~~~text
SET_VALVE fails with VM_RESULT_POWER_OFF
~~~

Client code must explicitly issue:

~~~text
POWER_ON
wait wake delay
SET_VALVE
~~~

### 9.4 Discovery Rule

Discovery is diagnostic/commissioning behavior.

It is not required for normal operation.

The client configuration is the normal source of truth for expected nodes and valves.

## 10. Recommended C Constants

~~~c
#ifndef VALVE_MASTER_I2C_H
#define VALVE_MASTER_I2C_H

#define VM_I2C_ADDR              0x09

#define VM_REG_COMMAND           0x00
#define VM_REG_STATUS            0x01
#define VM_REG_CURRENT_NODE      0x02
#define VM_REG_NODE_COUNT        0x03
#define VM_REG_ARG0              0x04
#define VM_REG_ARG1              0x05
#define VM_REG_POWER_STATE       0x06
#define VM_REG_LAST_RESULT       0x07
#define VM_REG_MASTER_VERSION_HI 0x08
#define VM_REG_MASTER_VERSION_LO 0x09
#define VM_REG_MASTER_PROTOCOL   0x0A
#define VM_REG_NODE_INFO_ID      0x10
#define VM_REG_NODE_VERSION_HI   0x11
#define VM_REG_NODE_VERSION_LO   0x12
#define VM_REG_NODE_PROTOCOL     0x13
#define VM_REG_NODE_VALVE_COUNT  0x14
#define VM_REG_NODE_BOARD_TYPE   0x15
#define VM_REG_NODE_MAP          0x20
#define VM_NODE_MAP_BYTES        32

#define VM_CMD_NONE              0x00
#define VM_CMD_WHO_SCAN          0x01
#define VM_CMD_SET_VALVE         0x02
#define VM_CMD_POWER_ON          0x03
#define VM_CMD_POWER_OFF         0x04
#define VM_CMD_GET_NODE_INFO     0x05

#define VM_STATUS_READY          0x01
#define VM_STATUS_BUSY           0x02
#define VM_STATUS_MAP_VALID      0x04
#define VM_STATUS_ERROR          0x08
#define VM_STATUS_POWER_ON       0x10

#define VM_POWER_OFF             0x00
#define VM_POWER_ON              0x01

#define VM_RESULT_OK             0x00
#define VM_RESULT_BUSY           0x01
#define VM_RESULT_BAD_NODE       0x02
#define VM_RESULT_BAD_ARGUMENT   0x03
#define VM_RESULT_NODE_NOT_FOUND 0x04
#define VM_RESULT_RS485_TIMEOUT  0x05
#define VM_RESULT_RS485_ERROR    0x06
#define VM_RESULT_POWER_OFF      0x07
#define VM_RESULT_BAD_COMMAND    0x08

#define VM_VALVE_STATE_BIT       0x80
#define VM_VALVE_INDEX_MASK      0x07
#define VM_VALVE_RESERVED_MASK   0x78

#endif
~~~

## 11. First Firmware Implementation Target

Implement first:

~~~text
POWER_ON
POWER_OFF
SET_VALVE
WHO_SCAN
GET_NODE_INFO
STATUS reads
LAST_RESULT reads
MASTER_VERSION reads
NODE_INFO reads
NODE_MAP reads
~~~

Do not implement yet:

~~~text
command queueing
automatic relay holdoff
automatic slave wake delay
automatic discovery on boot
automatic node capability negotiation
address assignment
abort command
~~~

This keeps the firmware target clean and testable while allowing diagnostics and future slave-node capability reporting.

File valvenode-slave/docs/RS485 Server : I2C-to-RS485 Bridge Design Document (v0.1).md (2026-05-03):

# RS485 Server / I2C-to-RS485 Bridge Design Document (v0.1)

**Date:** April 9, 2026

**Project Goal**

This board acts as a simple, reliable bridge between a Raspberry Pi (5 V I2C master) and the RS-485 bus that controls multiple valve nodes. It receives high-level commands over I2C and converts them into the framed ASCII protocol used by the valve nodes.

The design follows the same principles as the powercontrol board: boring, deterministic, minimal part count, easy to debug, and fully offline.

## 1. Purpose and Scope

- Receive commands from the Raspberry Pi over I2C (5 V)
- Convert and forward them as framed ASCII protocol over RS-485 at 19200 baud
- Support the full valve node command set (PING, STATUS, OPEN, CLOSE, WHO, etc.)
- Provide visual feedback with two LEDs (status + comm activity)
- Stay simple and inspectable — no complex state machines

This is a pure protocol bridge. No autonomous irrigation logic lives here.

## 2. High-Level Operation

1. Raspberry Pi sends a command packet over I2C.
2. The ATmega88PB receives the I2C data, validates it, and builds the correct framed RS-485 message.
3. The bridge transmits the frame on the RS-485 bus (with proper DE timing).
4. Any reply from a valve node is forwarded back to the Pi over I2C.
5. LEDs provide immediate visual feedback.

The bridge is transparent — it does not interpret the valve commands, only translates and forwards them.

## 3. Major Components

- **MCU**: ATmega88PB-AU (TQFP-32)
- **Clock**: Internal 8 MHz RC oscillator
- **I2C**: 5 V I2C slave (address to be decided, e.g. 0x08 like powercontrol)
- **RS-485**: Half-duplex at 19200 baud, 8N1
- **RS-485 Transceiver**: Standard 5 V part (e.g. MAX485, SP3485, or SN65HVD72)
- **Status LEDs**: Two LEDs (general status + RS-485 activity)
- **Power**: 5 V from the Raspberry Pi or local regulator

## 4. Pin Assignment

| Pin | Function | Direction | Notes |
|---|---|---|---|
| PC4 | SDA (I²C) | Bidirectional | 5 V I2C from Raspberry Pi |
| PC5 | SCL (I²C) | Output | 5 V I2C from Raspberry Pi |
| PB3 | MOSI (ISP) | - | ISP programming |
| PB4 | MISO (ISP) | - | ISP programming |
| PB5 | SCK (ISP) | - | ISP programming |
| PD0 | USART RX | Input | From RS-485 transceiver RO |
| PD1 | USART TX | Output | To RS-485 transceiver DI |
| PD2 | RS485_DE | Output | High = transmit, Low = receive (DE and /RE tied together) |
| PB0 | Status LED | Output | General status / ready indicator |
| PB1 | Comm LED | Output | RS-485 activity (blink on TX or RX) |
| PD3 | Spare | - | Available for future use |

All other pins remain free.

## 5. Power and Protection

- 5 V supplied directly from the Raspberry Pi (I2C is already 5 V)
- Optional local 5 V regulator if you want isolation
- Series resistors on I2C lines (like powercontrol)
- TVS or clamping diodes on RS-485 A/B lines recommended for field use
- Proper grounding between Pi and this board

## 6. Firmware Behavior

- I2C slave mode, simple command/response
- Receive command from Pi → build and send framed ASCII message on RS-485
- Receive reply from valve node → forward to Pi over I2C
- Blink Comm LED on every transmitted or received byte
- Status LED indicates ready / error state
- Watchdog enabled for robustness

The protocol on the RS-485 side remains exactly the same as the valve nodes:
 
```
@|LEN|COMMAND[|ARG1[|ARG2...]]|CHECKSUM<CR>
``` 

## 7. Recommended Connectors

- 4-pin header or screw terminal for RS-485 (A, B, +5 V, GND)
- Standard I2C header to Raspberry Pi
- 6-pin ISP header for programming
- Test points or header for the two LEDs

## 8. Bring-Up Checklist

1. Verify 5 V power and I2C communication from Pi
2. Verify ISP programming works with PB3/PB4/PB5
3. Verify USART TX/RX and DE pin toggling with a scope
4. Test basic PING command end-to-end (Pi → bridge → valve node → reply)
5. Verify LED behavior
6. Test WHO broadcast discovery

## 9. Known Limits (Rev A)

- Single RS-485 bus only
- No advanced error recovery or buffering yet
- I2C address and command format still to be finalized

## 10. Next Steps

- Finalize I2C command set (mirroring valve protocol where possible)
- Write initial firmware skeleton
- Decide on exact I2C address and packet format
- Add basic watchdog and timeout handling
- Bench test with one or more valve nodes

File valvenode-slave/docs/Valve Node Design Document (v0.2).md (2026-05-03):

# Standalone Valve Node Design Document (v0.2)

**Date:** April 9, 2026

**Sources of Truth:**
- `valvenode.c`
- Valve node protocol draft
- Locked node concept from this conversation

## 1. Purpose and Scope (Goal)

The valve node is a small remote controller for a **single 12 V latching irrigation valve**. It is intended to sit near the valve and receive commands from a master over a shared serial bus.

Core design goals:
- Fully offline, no cloud, no wireless dependency
- Simple 4-wire field connection:
  - +12 V
  - GND
  - RS-485 A
  - RS-485 B
- Small AVR with minimal part count
- Deterministic and inspectable behavior
- Local generation of the valve pulse using a VNH7100BAS H-bridge driver
- simple firmware, easy bench debug, easy field replacement

This document describes the **single-channel node** only.

## 2. How It Works (High-Level Overview)

1. The master sends a framed serial command over RS-485.
2. The node receives the frame and checks:
   - framing
   - payload length
   - optionally checksum
   - destination address
3. If the command is for this node:
   - `OPEN` sends one polarity pulse to the valve
   - `CLOSE` sends the opposite polarity pulse
   - `STATUS` reports current logical state
   - `PING` returns an ACK
4. If the command is broadcast `WHO|255`, each node waits a delay based on node address, then replies with its ID.
5. After the pulse, the bridge is turned fully off.

This is a simple command/response node. It is not autonomous irrigation logic.

## 3. System Overview – Major Components

- **MCU**: ATtiny4313
- **Bus Interface**: 5 V RS-485 transceiver
- **Valve Driver**: VNH7100BAS / VNH7100BASTR
- **Valve Type**: 12 V latching irrigation valve
- **Power Input**: 12 V nominal
- **Logic Supply**: Pololu D24V22F5 5 V regulator from 12 V input
- **Optional Status LED**: one MCU-driven LED

## 4. Power Architecture

- **Input power**: 12 VDC from field cable
- **Direct high-current path**: 12 V to VNH7100BAS motor supply
- **Logic rail**: Pololu D24V22F5 5 V step-down regulator for MCU and RS-485 transceiver

**Recommended components and layout for Rev A boards (16 nodes, master power switching):**

- **TVS diode**: 1.5KE15CA or P6KE15CA bidirectional across the 12 V input terminals
- **Bulk capacitance on 12 V rail**: 470 µF electrolytic capacitor (25 V or 35 V rating) + 0.1 µF ceramic capacitor, placed physically close to the VNH7100BAS motor supply pins and Pololu VIN pin
- **Pololu additional capacitance**: 47–100 µF electrolytic on VIN
- **5 V rail**: 10–47 µF electrolytic capacitor near the ATtiny4313 VCC pin
- 0.1 µF decoupling at MCU (pins 20 and 10) and RS-485 transceiver
- Separate local bulk cap on 5 V rail

**Field Cable Recommendation**: Use standard 4-conductor direct-burial irrigation sprinkler cable (18/4 acceptable for short runs; 16/4 recommended for longer runs or 16 nodes to minimize voltage drop during valve pulses).

**Note for master-side power switching (16 nodes):** The bulk capacitance handles inrush and valve pulse current when the DSP1-L2-DC12V relay turns the 12 V bus on. Allow 250–300 ms after power-on before sending commands.

Recommended basics:
- reverse polarity protection on 12 V input
- TVS diode on 12 V input
- local bulk capacitance near the VNH supply pins
- 0.1 µF decoupling at MCU and transceiver
- separate local bulk cap on 5 V rail

### Power Notes

The VNH7100BAS drives the valve pulse from the 12 V input supply. The MCU does not generate PWM for speed control. The VNH `PWM` pin is used only as an **enable gate**.

Safe default:
- `PWM = low`
- `INA = low`
- `INB = low`

That keeps the bridge off at reset and idle.

## 5. MCU Details and Pin Assignments

**MCU Part Number**: ATtiny4313  
**Package**: 20-pin DIP or equivalent package variant  
**Clock**: Internal 8 MHz RC oscillator  
**Voltage**: 5 V

### MCU Specs
- Flash: 4 KB
- SRAM: 256 B
- EEPROM: 256 B
- One hardware UART
- Enough GPIO for one valve node

### Locked Design Decisions
- UART used for command and reply traffic
- RS-485 is half duplex
- One GPIO controls RS-485 DE and /RE together
- VNH7100BAS `PWM` pin is enable only
- Single valve channel only
- Node address compiled in at build time for now

### Power Pins
Wire the MCU power pins in the schematic explicitly.

Recommended:
- VCC to +5 V
- GND to common ground
- 0.1 µF ceramic at the MCU supply pins
- 4.7–10 µF local bulk cap near MCU if convenient

### Reset / Programming
- Standard AVR ISP header recommended
- Keep RESET available
- Do not get cute with fuse settings unless you actually need to

## 6. ATtiny4313 Full Physical Pin Assignment for PDIP-20 and SOIC-20

This section lists the **complete physical pinout** for the ATtiny4313 in **PDIP-20** and **SOIC-20**. For these two packages, the **pin numbers and signal names are the same**. Only the package body changes.  

### Package-wide pin map

| Physical Pin | AVR Signal | Alternate Functions | Valve Node Use |
|---|---|---|---|
| 1  | PA2 | PCINT10 / RESET / dW | RESET, ISP programming |
| 2  | PD0 | PCINT11 / RXD | 485_RX (UART_RX from RS-485 transceiver RO) |
| 3  | PD1 | PCINT12 / TXD | 485_TX (UART_TX to RS-485 transceiver DI) |
| 4  | PA1 | PCINT9 / XTAL2 | Spare |
| 5  | PA0 | PCINT8 / CLKI / XTAL1 | Spare |
| 6  | PD2 | PCINT13 / CKOUT / XCK / INT0 | 485_DE |
| 7  | PD3 | PCINT14 / INT1 | Spare |
| 8  | PD4 | PCINT15 / T0 | VNH1_EN (PWM enable – first valve) |
| 9  | PD5 | PCINT16 / OC0B / T1 | VNH2_INB (second valve) |
| 10 | GND | Ground | Ground |
| 11 | PD6 | PCINT17 / ICP1 | VNH2_EN (PWM enable – second valve) |
| 12 | PB0 | AIN0 / PCINT0 | STATUS (Status LED) |
| 13 | PB1 | AIN1 / PCINT1 | VNH2_INA (second valve) |
| 14 | PB2 | OC0A / PCINT2 | VNH1_INB (first valve) |
| 15 | PB3 | OC1A / PCINT3 | VNH1_INA (first valve) |
| 16 | PB4 | OC1B / PCINT4 | Spare (optional second LED) |
| 17 | PB5 | MOSI / DI / SDA / PCINT5 | MOSI (ISP) |
| 18 | PB6 | MISO / DO / PCINT6 | MISO (ISP) |
| 19 | PB7 | USCK / SCL / SCK / PCINT7 | SCK (ISP) |
| 20 | VCC | Supply | +5 V logic supply |

### valve node assignments

These are the pins currently assigned by firmware and should stay aligned with `valvenode.c`.

| Function | AVR Signal | Physical Pin | Direction | Notes |
|---|---|---|---|---|
| UART_RX | PD0 | 2 | Input | From RS-485 transceiver RO |
| UART_TX | PD1 | 3 | Output | To RS-485 transceiver DI |
| RS485_DE | PD2 | 6 | Output | 1 = transmit, 0 = receive (DE and /RE tied) |
| VNH1_INA | PB3 | 15 | Output | First valve – H-bridge direction input A |
| VNH1_INB | PB2 | 14 | Output | First valve – H-bridge direction input B |
| VNH1_EN | PD4 | 8 | Output | First valve – PWM enable (H-bridge enable only) |
| VNH2_INA | PB1 | 13 | Output | Second valve – H-bridge direction input A |
| VNH2_INB | PD5 | 9 | Output | Second valve – H-bridge direction input B |
| VNH2_EN | PD6 | 11 | Output | Second valve – PWM enable (H-bridge enable only) |
| STATUS_LED | PB0 | 12 | Output | Status / ready LED |
| RESET | PA2 | 1 | Input | Keep for ISP programming |
| VCC | VCC | 20 | Power | +5 V logic supply |
| GND | GND | 10 | Power | Ground |

### Pins reserved but currently unused in Rev A (Dual Valve)

These are available on the package but are **not assigned in the current dual valve node firmware**.

| Physical Pin | AVR Signal | Notes |
|---|---|---|
| 4 | PA1 | Unused / Spare |
| 5 | PA0 | Unused / Spare |
| 7 | PD3 | Unused / Spare |
| 16 | PB4 | Spare (optional second LED or other function) |
| 17 | PB5 | MOSI (ISP programming) |
| 18 | PB6 | MISO (ISP programming) |
| 19 | PB7 | SCK (ISP programming) |

### Board design notes

- Put the **0.1 µF decoupler** close to pins **20 (VCC)** and **10 (GND)**.
- Keep **pin 1 RESET** accessible for AVR ISP.
- Keep the **RS-485 traces** away from the high-current valve output path.
- Keep the **VNH output current loop** physically separated from the MCU and UART area.
- Do not leave `VNH_PWM_EN` floating at reset. The firmware assumes it comes up off.
- If you use PB5/PB6/PB7 later, remember those overlap common serial-programming functions and can make bring-up more annoying if you get sloppy.

### Package note

This section applies to:
- **ATtiny4313-PU** in PDIP-20
- **ATtiny4313** in SOIC-20

The pin mapping above is taken from the official ATtiny2313A/4313 pinout figure.

## 7. RS-485 Interface Wiring

Use a standard half-duplex RS-485 transceiver.

### Required signals

| RS-485 Transceiver Pin | Connect To | Notes |
|---|---|---|
| DI | MCU TX (PD1) | UART transmit data |
| RO | MCU RX (PD0) | UART receive data |
| DE | MCU PB0 | Tie to /RE for one-pin direction control |
| /RE | MCU PB0 | Active low receive enable |
| A | Bus A | Field bus |
| B | Bus B | Field bus |
| VCC | +5 V | Logic supply |
| GND | GND | Common logic ground |

### RS-485 Notes
- Tie `DE` and `/RE` together for one-pin control
- Default to receive mode at boot
- Put termination only where appropriate for the bus layout
- Do not scatter termination all over the property like confetti
- Biasing should usually live at the master, not every node

## 8. VNH7100BAS Wiring

The VNH7100BAS is used as a bidirectional pulse driver for the latching valve.

### Control Signals

### VNH7100BAS Wiring (Dual Valve Node v0.3)

**VNH1 (First Valve)**

| VNH Pin | Connect To | Notes |
|---|---|---|
| INA | MCU PB3 | Direction control – first valve |
| INB | MCU PB2 | Direction control – first valve |
| PWM | MCU PD4 | Enable only (H-bridge enable) |
| SEL0 | Fixed logic level | Leave simple for rev A |
 
**VNH2 (Second Valve)**

| VNH Pin | Connect To | Notes |
|---|---|---|
| INA | MCU PB1 | Direction control – second valve |
| INB | MCU PD5 | Direction control – second valve |
| PWM | MCU PD6 | Enable only (H-bridge enable) |
| SEL0 | Fixed logic level | Leave simple for rev A |
 
### Power / Output

| VNH Pin Group | Connect To | Notes |
|---|---|---|
| Motor supply  | +12 V | Bulk decoupling required nearby |
| Power ground  | GND | Heavy return path |
| OUTA / OUTB | Valve coil | Two-wire latching valve |

### Recommended control sequence

**OPEN pulse**
1. Set `INA = 1`, `INB = 0`
2. Wait about 20 µs
3. Set `PWM = 1`
4. Hold for pulse duration
5. Set `PWM = 0`
6. Return inputs to safe state if desired

**CLOSE pulse**
1. Set `INA = 0`, `INB = 1`
2. Wait about 20 µs
3. Set `PWM = 1`
4. Hold for pulse duration
5. Set `PWM = 0`
6. Return inputs to safe state

Current firmware pulse width:
- **50 ms**

That value is only a starting point. The real valve should be tested.

## 9. Valve Wiring

The valve is a simple two-wire latching coil.

| Valve Lead | Connect To |
|---|---|
| Lead 1 | VNH output A |
| Lead 2 | VNH output B |

The node reverses polarity to open vs close the valve.

This is the entire point of using the H-bridge.

## 10. Recommended Connectors

### Field bus / power input
4-position terminal block:
1. +12 V
2. GND
3. RS-485 A
4. RS-485 B

**Field cable recommendation:** Use standard 4-conductor direct-burial irrigation sprinkler cable (18/4 or 16/4 preferred for longer runs or 16 nodes).

### Valve output
2-position terminal block:
1. Valve A
2. Valve B

### Programming
6-pin AVR ISP header

That is enough. No beauty contest hardware needed.

## 11. Firmware Behavior

### Supported commands
- `PING`
- `STATUS`
- `OPEN`
- `CLOSE`
- `WHO`

### Replies
- `ACK|addr`
- `STATE|addr|OPEN`
- `STATE|addr|CLOSED`
- `ID|addr`
- `ERR|addr|BADCMD`

### Current protocol format
ASCII framed protocol:

~~~text
@|LEN|COMMAND[|ARG1[|ARG2...]]|CHECKSUM<CR>
~~~

Examples:
~~~text
@|6|OPEN|1|E0
@|7|CLOSE|1|4F
@|8|STATUS|1|57
@|7|WHO|255|0D
~~~

Current firmware option:
- `IGNORE_RX_CHECKSUM = 1` may be used during bring-up

## 12. Boot and Safe State Requirements

At reset and startup:
- RS-485 should default to receive mode
- VNH `PWM` must be low
- VNH `INA` and `INB` must be low
- Valve must not receive any accidental pulse

This matters more than clever protocol junk.

## 13. Bring-Up Checklist

1. Verify +12 V input polarity
2. Verify regulator output is +5 V
3. Verify MCU clock and UART alive
4. Verify RS-485 receive path
5. Verify `PING` reply
6. Verify VNH control pins with a scope
7. Verify `OPEN` pulse width
8. Verify `CLOSE` pulse width
9. Verify valve actuates reliably
10. Verify no idle current path through the valve

## 14. Known Limits of Rev A

- Single valve channel only
- No current sensing
- No supply voltage telemetry
- No capacitor-bank telemetry
- No EEPROM address provisioning yet
- No watchdog/recovery logic documented here
- No hardware fault reporting from MultiSense in use yet

That is fine for a first board.

## 15. Recommended Next Steps

- Add watchdog
- Add simple brownout sanity checks
- Decide whether node ID stays compile-time or moves to EEPROM
- Decide whether MultiSense is worth reading
- Bench test real valve pulse current and required pulse width
- Confirm idle current in the full node

## 16. Summary

This node is intentionally plain:

- ATtiny4313
- RS-485 UART
- VNH7100BAS as a simple polarity-reversing pulse driver
- one valve
- 12 V power input
- 5 V logic
- boring framed ASCII protocol

That is the right level of complexity for rev A.

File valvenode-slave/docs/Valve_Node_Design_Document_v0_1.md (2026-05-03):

# Standalone Valve Node Design Document (v0.1)

**Date:** April 7, 2026

**Sources of Truth:**
- `valvenode.c`
- Valve node protocol draft
- Locked node concept from this conversation

## 1. Purpose and Scope (Goal)

The valve node is a small remote controller for a **single 12 V latching irrigation valve**. It is intended to sit near the valve and receive commands from a master over a shared serial bus.

Core design goals:
- Fully offline, no cloud, no wireless dependency
- Simple 4-wire field connection:
  - +12 V
  - GND
  - RS-485 A
  - RS-485 B
- Small AVR with minimal part count
- Deterministic and inspectable behavior
- Local generation of the valve pulse using a VNH7100BAS H-bridge driver
- Boring firmware, easy bench debug, easy field replacement

This document describes the **single-channel node** only.

## 2. How It Works (High-Level Overview)

1. The master sends a framed serial command over RS-485.
2. The node receives the frame and checks:
   - framing
   - payload length
   - optionally checksum
   - destination address
3. If the command is for this node:
   - `OPEN` sends one polarity pulse to the valve
   - `CLOSE` sends the opposite polarity pulse
   - `STATUS` reports current logical state
   - `PING` returns an ACK
4. If the command is broadcast `WHO|255`, each node waits a delay based on node address, then replies with its ID.
5. After the pulse, the bridge is turned fully off.

This is a simple command/response node. It is not autonomous irrigation logic.

## 3. System Overview – Major Components

- **MCU**: ATtiny4313
- **Bus Interface**: 5 V RS-485 transceiver
- **Valve Driver**: VNH7100BAS / VNH7100BASTR
- **Valve Type**: 12 V latching irrigation valve
- **Power Input**: 12 V nominal
- **Logic Supply**: 5 V regulator from 12 V input
- **Optional Status LED**: one MCU-driven LED

## 4. Power Architecture

- **Input power**: 12 VDC from field cable
- **Direct high-current path**: 12 V to VNH7100BAS motor supply
- **Logic rail**: local 5 V regulator for MCU and RS-485 transceiver

Recommended basics:
- reverse polarity protection on 12 V input
- TVS diode on 12 V input
- local bulk capacitance near the VNH supply pins
- 0.1 µF decoupling at MCU and transceiver
- separate local bulk cap on 5 V rail

### Power Notes

The VNH7100BAS drives the valve pulse from the 12 V input supply. The MCU does not generate PWM for speed control. The VNH `PWM` pin is used only as an **enable gate**.

Safe default:
- `PWM = low`
- `INA = low`
- `INB = low`

That keeps the bridge off at reset and idle.

## 5. MCU Details and Pin Assignments

**MCU Part Number**: ATtiny4313  
**Package**: 20-pin DIP or equivalent package variant  
**Clock**: Internal 8 MHz RC oscillator  
**Voltage**: 5 V

### MCU Specs
- Flash: 4 KB
- SRAM: 256 B
- EEPROM: 256 B
- One hardware UART
- Enough GPIO for one valve node

### Locked Design Decisions
- UART used for command and reply traffic
- RS-485 is half duplex
- One GPIO controls RS-485 DE and /RE together
- VNH7100BAS `PWM` pin is enable only
- Single valve channel only
- Node address compiled in at build time for now

### Power Pins
Wire the MCU power pins in the schematic explicitly.

Recommended:
- VCC to +5 V
- GND to common ground
- 0.1 µF ceramic at the MCU supply pins
- 4.7–10 µF local bulk cap near MCU if convenient

### Reset / Programming
- Standard AVR ISP header recommended
- Keep RESET available
- Do not get cute with fuse settings unless you actually need to

## 6. ATtiny4313 Full Physical Pin Assignment for PDIP-20 and SOIC-20

This section lists the **complete physical pinout** for the ATtiny4313 in **PDIP-20** and **SOIC-20**. For these two packages, the **pin numbers and signal names are the same**. Only the package body changes.  [oai_citation:1‡Microchip](https://ww1.microchip.com/downloads/en/DeviceDoc/doc8246.pdf)

### Package-wide pin map

| Physical Pin | AVR Signal | Alternate Functions | Valve Node Use |
|---|---|---|---|
| 1  | PA2 | PCINT10 / RESET / dW | RESET, ISP programming |
| 2  | PD0 | PCINT11 / RXD | UART_RX from RS-485 transceiver RO |
| 3  | PD1 | PCINT12 / TXD | UART_TX to RS-485 transceiver DI |
| 4  | PA1 | PCINT9 / XTAL2 | Spare |
| 5  | PA0 | PCINT8 / CLKI / XTAL1 | Spare |
| 6  | PD2 | PCINT13 / CKOUT / XCK / INT0 | Spare |
| 7  | PD3 | PCINT14 / INT1 | Spare |
| 8  | PD4 | PCINT15 / T0 | Spare |
| 9  | PD5 | PCINT16 / OC0B / T1 | Spare |
| 10 | GND | Ground | Ground |
| 11 | PD6 | PCINT17 / ICP1 | Spare |
| 12 | PB0 | AIN0 / PCINT0 | RS485_DE_RE |
| 13 | PB1 | AIN1 / PCINT1 | VNH_INA |
| 14 | PB2 | OC0A / PCINT2 | VNH_INB |
| 15 | PB3 | OC1A / PCINT3 | VNH_PWM_EN |
| 16 | PB4 | OC1B / PCINT4 | STATUS_LED |
| 17 | PB5 | MOSI / DI / SDA / PCINT5 | Spare, possible ISP/data use |
| 18 | PB6 | MISO / DO / PCINT6 | Spare, possible ISP/data use |
| 19 | PB7 | USCK / SCL / SCK / PCINT7 | Spare, possible ISP/clock use |
| 20 | VCC | Supply | +5 V logic supply |

### Locked valve node assignments

These are the pins currently assigned by firmware and should stay aligned with `valvenode.c`.

| Function | AVR Signal | Physical Pin | Direction | Notes |
|---|---|---|---|---|
| UART_RX | PD0 | 2  | Input  | From RS-485 transceiver RO |
| UART_TX | PD1 | 3  | Output | To RS-485 transceiver DI |
| RS485_DE_RE  | PB0 | 12 | Output | 1 = transmit, 0 = receive |
| VNH_INA | PB1 | 13 | Output | H-bridge direction input A |
| VNH_INB | PB2 | 14 | Output | H-bridge direction input B |
| VNH_PWM_EN | PB3 | 15 | Output | H-bridge enable only, not real PWM |
| STATUS_LED | PB4 | 16 | Output | Optional status LED |
| RESET | PA2 | 1  | Input  | Keep for ISP programming |
| VCC | VCC | 20 | Power  | +5 V |
| GND | GND | 10 | Power  | Ground |

### Pins reserved but currently unused in Rev A

These are available on the package but are **not assigned in the current valve node firmware**.

| Physical Pin | AVR Signal | Notes |
|---|---|---|
| 4  | PA1 | Unused |
| 5  | PA0 | Unused |
| 6  | PD2 | Unused |
| 7  | PD3 | Unused |
| 8  | PD4 | Unused |
| 9  | PD5 | Unused |
| 11 | PD6 | Unused |
| 17 | PB5 | Unused, overlaps common ISP/data functions |
| 18 | PB6 | Unused, overlaps common ISP/data functions |
| 19 | PB7 | Unused, overlaps common ISP/clock functions |

### Board design notes

- Put the **0.1 µF decoupler** close to pins **20 (VCC)** and **10 (GND)**.
- Keep **pin 1 RESET** accessible for AVR ISP.
- Keep the **RS-485 traces** away from the high-current valve output path.
- Keep the **VNH output current loop** physically separated from the MCU and UART area.
- Do not leave `VNH_PWM_EN` floating at reset. The firmware assumes it comes up off.
- If you use PB5/PB6/PB7 later, remember those overlap common serial-programming functions and can make bring-up more annoying if you get sloppy.

### Package note

This section applies to:
- **ATtiny4313-PU** in PDIP-20
- **ATtiny4313** in SOIC-20

The pin mapping above is taken from the official ATtiny2313A/4313 pinout figure.  [oai_citation:2‡Microchip](https://ww1.microchip.com/downloads/en/DeviceDoc/doc8246.pdf)

## 7. RS-485 Interface Wiring

Use a standard half-duplex RS-485 transceiver.

### Required signals

| RS-485 Transceiver Pin | Connect To | Notes |
|---|---|---|
| DI | MCU TX (PD1) | UART transmit data |
| RO | MCU RX (PD0) | UART receive data |
| DE | MCU PB0 | Tie to /RE for one-pin direction control |
| /RE | MCU PB0 | Active low receive enable |
| A | Bus A | Field bus |
| B | Bus B | Field bus |
| VCC | +5 V | Logic supply |
| GND | GND | Common logic ground |

### RS-485 Notes
- Tie `DE` and `/RE` together for one-pin control
- Default to receive mode at boot
- Put termination only where appropriate for the bus layout
- Do not scatter termination all over the property like confetti
- Biasing should usually live at the master, not every node

## 8. VNH7100BAS Wiring

The VNH7100BAS is used as a bidirectional pulse driver for the latching valve.

### Control Signals

| VNH Pin | Connect To | Notes |
|---|---|---|
| INA | MCU PB1 | Direction control |
| INB | MCU PB2 | Direction control |
| PWM | MCU PB3 | Enable only |
| SEL0 | Fixed logic level | Leave simple for rev A |
| MultiSense | Optional test point or NC | Not used in rev A logic |

### Power / Output

| VNH Pin Group | Connect To | Notes |
|---|---|---|
| Motor supply  | +12 V | Bulk decoupling required nearby |
| Power ground  | GND | Heavy return path |
| OUTA / OUTB | Valve coil | Two-wire latching valve |

### Recommended control sequence

**OPEN pulse**
1. Set `INA = 1`, `INB = 0`
2. Wait about 20 µs
3. Set `PWM = 1`
4. Hold for pulse duration
5. Set `PWM = 0`
6. Return inputs to safe state if desired

**CLOSE pulse**
1. Set `INA = 0`, `INB = 1`
2. Wait about 20 µs
3. Set `PWM = 1`
4. Hold for pulse duration
5. Set `PWM = 0`
6. Return inputs to safe state

Current firmware pulse width:
- **50 ms**

That value is only a starting point. The real valve should be tested.

## 9. Valve Wiring

The valve is a simple two-wire latching coil.

| Valve Lead | Connect To |
|---|---|
| Lead 1 | VNH output A |
| Lead 2 | VNH output B |

The node reverses polarity to open vs close the valve.

This is the entire point of using the H-bridge.

## 10. Recommended Connectors

### Field bus / power input
4-position terminal block:
1. +12 V
2. GND
3. RS-485 A
4. RS-485 B

### Valve output
2-position terminal block:
1. Valve A
2. Valve B

### Programming
6-pin AVR ISP header

That is enough. No beauty contest hardware needed.

## 11. Firmware Behavior

### Supported commands
- `PING`
- `STATUS`
- `OPEN`
- `CLOSE`
- `WHO`

### Replies
- `ACK|addr`
- `STATE|addr|OPEN`
- `STATE|addr|CLOSED`
- `ID|addr`
- `ERR|addr|BADCMD`

### Current protocol format
ASCII framed protocol:

~~~text
@|LEN|COMMAND[|ARG1[|ARG2...]]|CHECKSUM<CR>
~~~

Examples:
~~~text
@|6|OPEN|1|E0
@|7|CLOSE|1|4F
@|8|STATUS|1|57
@|7|WHO|255|0D
~~~

Current firmware option:
- `IGNORE_RX_CHECKSUM = 1` may be used during bring-up

## 12. Boot and Safe State Requirements

At reset and startup:
- RS-485 should default to receive mode
- VNH `PWM` must be low
- VNH `INA` and `INB` must be low
- Valve must not receive any accidental pulse

This matters more than clever protocol junk.

## 13. Bring-Up Checklist

1. Verify +12 V input polarity
2. Verify regulator output is +5 V
3. Verify MCU clock and UART alive
4. Verify RS-485 receive path
5. Verify `PING` reply
6. Verify VNH control pins with a scope
7. Verify `OPEN` pulse width
8. Verify `CLOSE` pulse width
9. Verify valve actuates reliably
10. Verify no idle current path through the valve

## 14. Known Limits of Rev A

- Single valve channel only
- No current sensing
- No supply voltage telemetry
- No capacitor-bank telemetry
- No EEPROM address provisioning yet
- No watchdog/recovery logic documented here
- No hardware fault reporting from MultiSense in use yet

That is fine for a first board.

## 15. Recommended Next Steps

- Add watchdog
- Add simple brownout sanity checks
- Decide whether node ID stays compile-time or moves to EEPROM
- Decide whether MultiSense is worth reading
- Bench test real valve pulse current and required pulse width
- Confirm idle current in the full node

## 16. Summary

This node is intentionally plain:

- ATtiny4313
- RS-485 UART
- VNH7100BAS as a simple polarity-reversing pulse driver
- one valve
- 12 V power input
- 5 V logic
- boring framed ASCII protocol

That is the right level of complexity for rev A.

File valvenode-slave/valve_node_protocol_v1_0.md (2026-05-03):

# Valve Node Serial Protocol v1.0

## Purpose

This protocol defines simple ASCII-framed communication between a master and one or more dual-valve slave nodes on a shared half-duplex serial bus such as RS-485.

The goals are:

- easy to read in a terminal
- easy to debug with a logic analyzer
- small enough for AVR firmware
- deterministic parsing and timing
- explicit node addressing
- simple broadcast discovery and configuration

This is not a binary protocol. Frames are ASCII text.

## Frame Format

Each request or reply has this structure:

~~~text
:DDC[A][B][KK]<EOL>
~~~

Where:

- `:` is the start-of-frame marker
- `DD` is a 2 hex digit node address
- `C` is a 1 character command or reply code
- `A` is an optional 1 character argument
- `B` is an optional 1 character second argument, used in some replies
- `KK` is an optional 2 hex digit checksum on requests, and a required 2 hex digit checksum on replies
- `<EOL>` may be `CR`, `LF`, or `CRLF`

Examples:

~~~text
:04P
:04O1
:04S2
:04V
:04PB4
:04S1B5
~~~

## Addressing

Address rules:

- `01` to `FE` are valid assigned node addresses
- `FF` is broadcast
- `00` is invalid for normal operation and represents an unassigned node

Notes:

- An unassigned node does not answer normal directed commands
- An unassigned node may accept `:00M` to enter config mode
- The master is not a node on this protocol and does not have a node address

## Checksum

Checksum is the 8-bit unsigned sum of the ASCII body bytes modulo 256.

Do not include:

- the leading `:`
- the final end-of-line

The checksum is transmitted as two ASCII hexadecimal digits.

### Example checksum calculation

Body:

~~~text
04P
~~~

ASCII bytes:

~~~text
'0' = 0x30
'4' = 0x34
'P' = 0x50
~~~

Sum:

~~~text
0x30 + 0x34 + 0x50 = 0xB4
~~~

So the request with checksum is:

~~~text
:04PB4
~~~

Replies always include checksum.

Requests may omit checksum.

## Command Set

### Directed commands

- `:DDP` ping node `DD`
- `:DDO1` open valve 1 on node `DD`
- `:DDC1` close valve 1 on node `DD`
- `:DDO2` open valve 2 on node `DD`
- `:DDC2` close valve 2 on node `DD`
- `:DDS1` read valve 1 state on node `DD`
- `:DDS2` read valve 2 state on node `DD`
- `:DDV` read firmware version from node `DD`
- `:DDI` put node `DD` into identify mode
- `:DDM` put node `DD` into config mode

### Special directed command for unassigned node

- `:00M` put an unassigned node into config mode

### Config-mode address assignment

- `:DDN` assign new address `DD`

Rules:

- `N` is only valid while the target node is already in config mode
- `00` and `FF` are not valid assigned addresses
- after successful assignment the node stores the new address in EEPROM, updates runtime address, replies using the new address, and exits config mode

### Broadcast commands

- `:FFW` broadcast WHO
- `:FFX` broadcast cancel special modes

`X` silently cancels:

- config mode
- identify mode

## Replies

The node uses these reply codes:

- `A` acknowledge
- `E` error
- `W` WHO response
- `R` valve state response
- `V` firmware version response
- `B` boot banner

### Examples

Ping reply from node 04:

~~~text
:04AA5
~~~

Valve 1 open reply from node 04:

~~~text
:04R1O42
~~~

Valve 1 closed reply from node 04:

~~~text
:04R1C36
~~~

WHO reply from node 04:

~~~text
:04WBB
~~~

Firmware version reply, version 1.00:

~~~text
:04V01004B
~~~

Boot banner from node 04:

~~~text
:04BA6
~~~

## Firmware Version Encoding

Firmware version is returned as 16-bit packed BCD, transmitted as 4 hexadecimal characters.

Examples:

- `0x0100` means version `1.00`
- `0x0215` means version `2.15`

Example reply:

~~~text
:04V01004B
~~~

## Valve State Replies

Status replies use command `R`.

Format:

~~~text
:DDRxyKK
~~~

Where:

- `x` is valve channel, `1` or `2`
- `y` is valve state:
  - `O` = open
  - `C` = closed

Examples:

~~~text
:04R1O42
:04R1C36
:04R2O43
:04R2C37
~~~

## Config Mode

Config mode is used for address management.

Entry methods:

- directed command `:DDM`
- boot-time local config button hold
- special directed command `:00M` for an unassigned node

Behavior:

- node blinks the LED in config pattern while in config mode
- config mode times out automatically if not completed
- successful address assignment exits config mode
- `:FFX` cancels config mode silently

## Identify Mode

Identify mode is used to physically locate a node in the field.

Entry method:

- directed command `:DDI`

Behavior:

- node continues to function normally while identifying
- LED blinks at the configured identify rate
- `:FFX` cancels identify mode silently

## Broadcast WHO Discovery

Broadcast WHO is used to discover assigned nodes on the bus.

Request:

~~~text
:FFW
~~~

Behavior for each assigned node:

1. verify the frame is a valid broadcast WHO
2. ignore the request if the node is still unassigned `00`
3. compute a deterministic reply delay based on node address
4. wait its slot time
5. send `W` reply containing its own address in the frame header

Slot timing rule:

~~~text
delay_ms = node_addr * WHO_SLOT_MS
~~~

Example with `WHO_SLOT_MS = 20 ms`:

- node `01` replies after about `20 ms`
- node `02` replies after about `40 ms`
- node `04` replies after about `80 ms`

Important:

- WHO replies must not add extra pre-reply LED delays, or slot timing will collide
- the master must wait long enough for all expected reply slots to expire

## Receiver Behavior

A receiver should:

1. wait for `:`
2. collect body characters until `CR` or `LF`
3. accept `CR`, `LF`, or `CRLF`
4. restart frame capture if a new `:` appears mid-frame
5. validate the frame length against the allowed command shapes
6. parse address and command
7. if checksum is present, verify it
8. dispatch only valid frames

Malformed frames should be discarded silently.

## Boot Behavior

At boot the node:

1. initializes GPIO and UART
2. loads node address from EEPROM into RAM
3. optionally checks the config button hold window
4. emits startup blink pattern
5. sends boot banner if the node has a valid assigned address

Unassigned node `00` stays quiet at boot.

## Example Commands

### Basic directed commands

~~~text
:04P
:04S1
:04S2
:04O1
:04O2
:04C1
:04C2
:04V
:04I
:04M
~~~

### Unassigned node enrollment

~~~text
:00M
:04N
:04P
:04V
~~~

### Broadcast commands

~~~text
:FFW
:FFX
~~~

### Commands with real checksums

~~~text
:04PB4
:04S1B5
:04S2B6
:04O1B1
:04O2B2
:04C1A5
:04C2A6
:04VB6
:04IB0
:04MB4
:00M9D
:04NB5
:FFW1C
:FFX1D
~~~

## Suggested Bench Test Order

Assigned node:

~~~text
:04P
:04V
:04S1
:04O1
:04S1
:04C1
:04S1
:04O2
:04S2
:04C2
:04S2
:04I
:FFX
:FFW
~~~

Unassigned node:

~~~text
:00M
:04N
:04P
:04V
:FFW
~~~

## Terminal Notes

- The parser accepts `CR`, `LF`, or `CRLF`
- A normal serial terminal is sufficient
- Do not paste multiple half-duplex request frames back-to-back without waiting for reply or timeout

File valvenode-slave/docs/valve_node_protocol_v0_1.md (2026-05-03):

# Valve Node Serial Protocol v0.1

## Purpose

This protocol is for simple ASCII-framed communication between a master and one or more valve nodes on a shared serial bus such as RS-485.

The goals are:

- easy to read on a terminal
- easy to debug with a logic analyzer
- simple enough for small AVR firmware
- deterministic parsing
- room to grow later

This is not a binary protocol. All fields are ASCII text.

## Frame Format

Each frame has this structure:

~~~text
@|LEN|COMMAND[|ARG1[|ARG2...]]|CHECKSUM<CR>
~~~

Where:

- `@` is the start-of-frame header
- `|` is the field separator
- `LEN` is the ASCII decimal payload length
- `COMMAND` is the command name
- `ARG1`, `ARG2`, and so on are optional ASCII arguments
- `CHECKSUM` is a two-digit ASCII hexadecimal checksum
- `<CR>` is carriage return, `0x0D`

No line feed is required.

## Basic Rules

1. Every frame starts with `@`.
2. Every frame ends with `<CR>`.
3. Fields are separated by the `|` character.
4. `LEN` is the character count of the text between the second `|` and the `|` immediately before `CHECKSUM`.
5. `CHECKSUM` is computed over the payload text only, not including:
   - the `@`
   - the `LEN`
   - the separators before the payload
   - the separator before `CHECKSUM`
   - the final `<CR>`
6. All command and argument text is ASCII.
7. Command names should be uppercase.
8. Nodes should ignore frames with bad checksum or malformed length.

## Payload Definition

The payload is everything from `COMMAND` through the last argument, joined by `|`.

Example payload:

~~~text
OPEN|7
~~~

In this example:

- `COMMAND = OPEN`
- `ARG1 = 7`
- payload length = 6 characters

Character count:

- `O` `P` `E` `N` = 4
- `|` = 1
- `7` = 1

Total = 6

## Length Field

`LEN` is ASCII decimal.

Examples:

- `4`
- `6`
- `12`

Leading zeroes should not be required, but a receiver may accept them.

Examples:

~~~text
@|4|PING|2A<CR>
@|6|OPEN|7|5F<CR>
@|13|STATUS|NODE1|91<CR>
~~~

## Checksum

Checksum is the 8-bit unsigned sum of all payload characters, modulo 256.

Transmit it as two ASCII hexadecimal digits, uppercase preferred.

### Example checksum calculation

Payload:

~~~text
OPEN|7
~~~

ASCII bytes:

~~~text
O  = 0x4F
P  = 0x50
E  = 0x45
N  = 0x4E
|  = 0x7C
7  = 0x37
~~~

Sum:

~~~text
0x4F + 0x50 + 0x45 + 0x4E + 0x7C + 0x37 = 0x1E5
~~~

Modulo 256:

~~~text
0xE5
~~~

Frame:

~~~text
@|6|OPEN|7|E5<CR>
~~~

## Addressing

The first argument after the command should normally be the destination node address unless the command is a broadcast command.

Recommended address rules:

- `1` to `254` are valid node addresses
- `255` is reserved for broadcast
- `0` is invalid or reserved

Examples:

~~~text
@|6|OPEN|7|E5<CR>
@|8|CLOSE|12|0D<CR>
@|10|STATUS|255|76<CR>
~~~

## Recommended Command Set

### Master to node

- `PING|addr`
- `STATUS|addr`
- `OPEN|addr`
- `CLOSE|addr`
- `WHO|255`

### Node to master replies

- `ACK|addr`
- `ERR|addr|code`
- `STATE|addr|OPEN`
- `STATE|addr|CLOSED`
- `ID|addr`

## Broadcast Discovery

To ask all nodes to identify themselves:

~~~text
@|7|WHO|255|CS<CR>
~~~

Each node that hears this valid broadcast should:

1. verify checksum
2. verify destination is `255`
3. compute a reply delay from its own node ID
4. wait its slot time
5. send an `ID|addr` reply

### Slot timing

Use a deterministic slot based on node address.

Example:

~~~text
delay_ms = node_addr * slot_ms
~~~

For a small system:

- baud rate: 19200
- slot time: 10 ms

Examples:

- node 1 replies at 10 ms
- node 2 replies at 20 ms
- node 7 replies at 70 ms

This avoids reply collisions as long as node IDs are unique.

## Receiver Behavior

A receiver should:

1. wait for `@`
2. collect bytes until `<CR>`
3. split fields on `|`
4. validate field count
5. parse `LEN`
6. rebuild payload text
7. verify payload length
8. compute checksum
9. dispatch command only if all checks pass

On failure, discard the frame.

## Error Handling

Recommended error codes:

- `BADLEN`
- `BADCS`
- `BADCMD`
- `BADADDR`
- `BUSY`

Example:

~~~text
@|14|ERR|7|BADCS|A8<CR>
~~~

## Safe Parsing Limits

For small AVR firmware, define fixed limits.

Recommended first cut:

- max full frame length: 64 bytes
- max payload length: 48 bytes
- max command length: 12 bytes
- max argument count: 4

If a frame exceeds limits, discard it.

## Examples

### Ping node 3

~~~text
@|6|PING|3|D4<CR>
~~~

Reply:

~~~text
@|5|ACK|3|C2<CR>
~~~

### Open node 7

~~~text
@|6|OPEN|7|E5<CR>
~~~

Reply:

~~~text
@|5|ACK|7|C6<CR>
~~~

### Ask node 7 for status

~~~text
@|8|STATUS|7|9E<CR>
~~~

Reply if open:

~~~text
@|12|STATE|7|OPEN|69<CR>
~~~

### Broadcast discovery

~~~text
@|7|WHO|255|1F<CR>
~~~

Possible replies over time:

~~~text
@|4|ID|1|16<CR>
@|4|ID|7|1C<CR>
@|5|ID|12|50<CR>
~~~

## Implementation Notes

- Keep command matching case-sensitive and uppercase.
- Do not allow nodes to reply to malformed broadcast frames.
- Do not allow a node to act on a command until length and checksum are both valid.
- Default idle state for the valve driver must be disabled.
- Replies should be short.

## Versioning

Protocol version should be tracked in firmware documentation, not necessarily inside every frame in rev A.

If needed later, add:

~~~text
PROTO|1
~~~

as part of a capability or identification response.

## Summary

This protocol is intentionally plain and boring:

- ASCII framing
- fixed header
- decimal length
- text commands
- 8-bit checksum
- `<CR>` terminator

That makes it easy to debug and easy to implement on a small AVR.

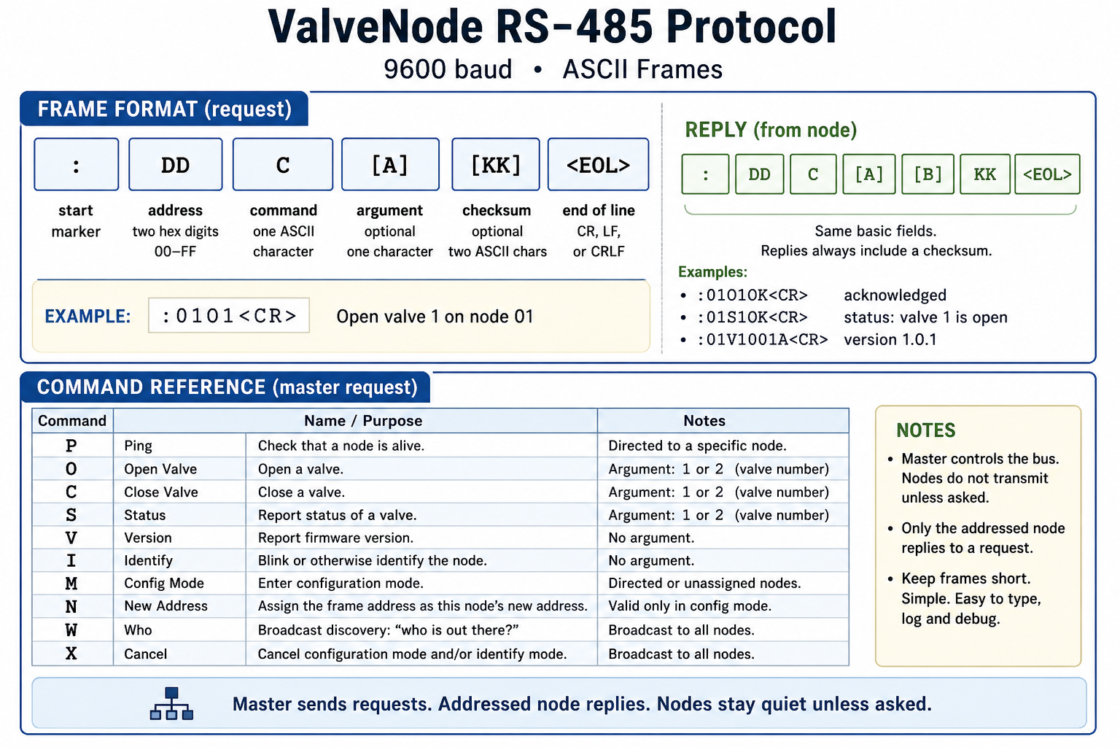
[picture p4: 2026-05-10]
valvenode-slave/docs/protocol.png

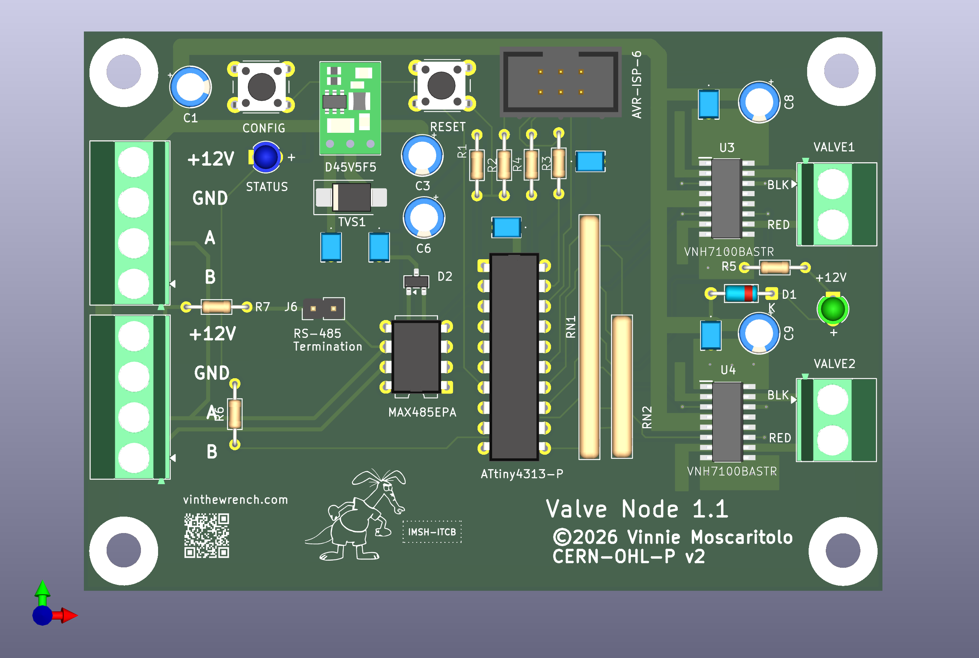
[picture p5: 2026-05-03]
valvenode-slave/hw/1.1/valvenode.png

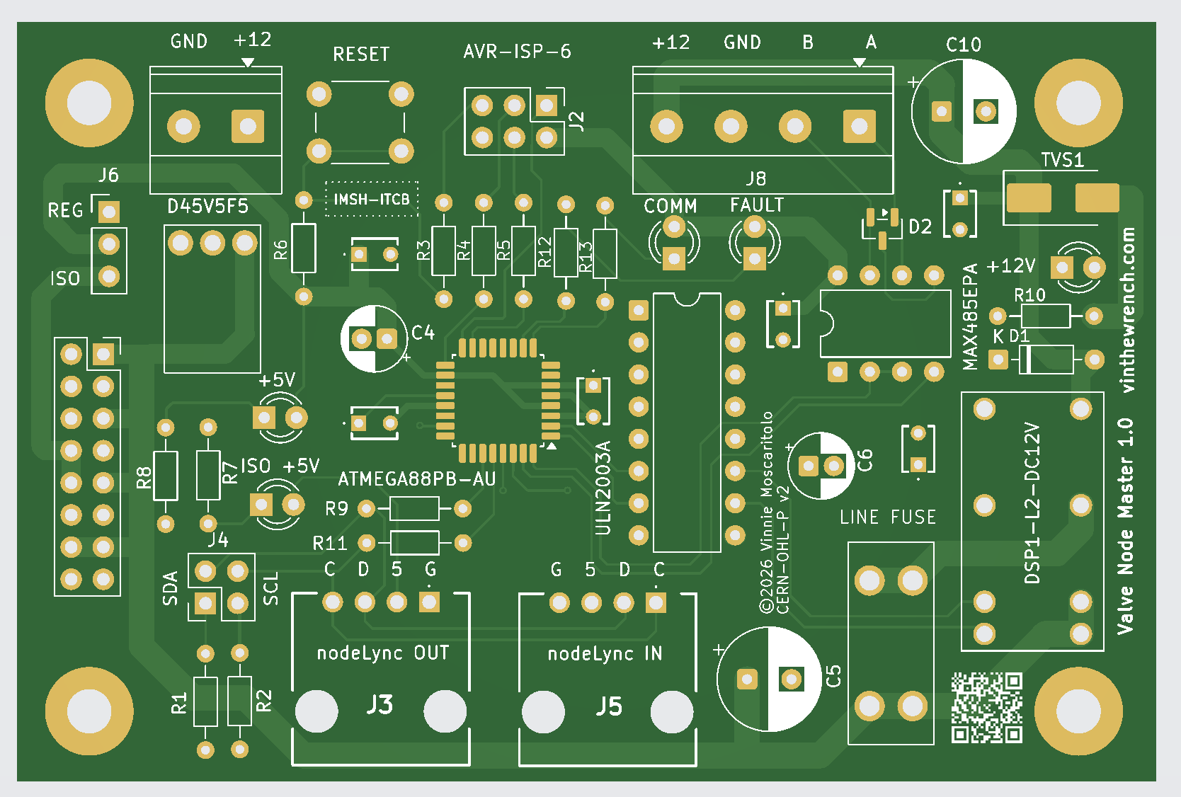
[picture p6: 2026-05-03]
valvenode-master/hw/1.0/PCB front.png

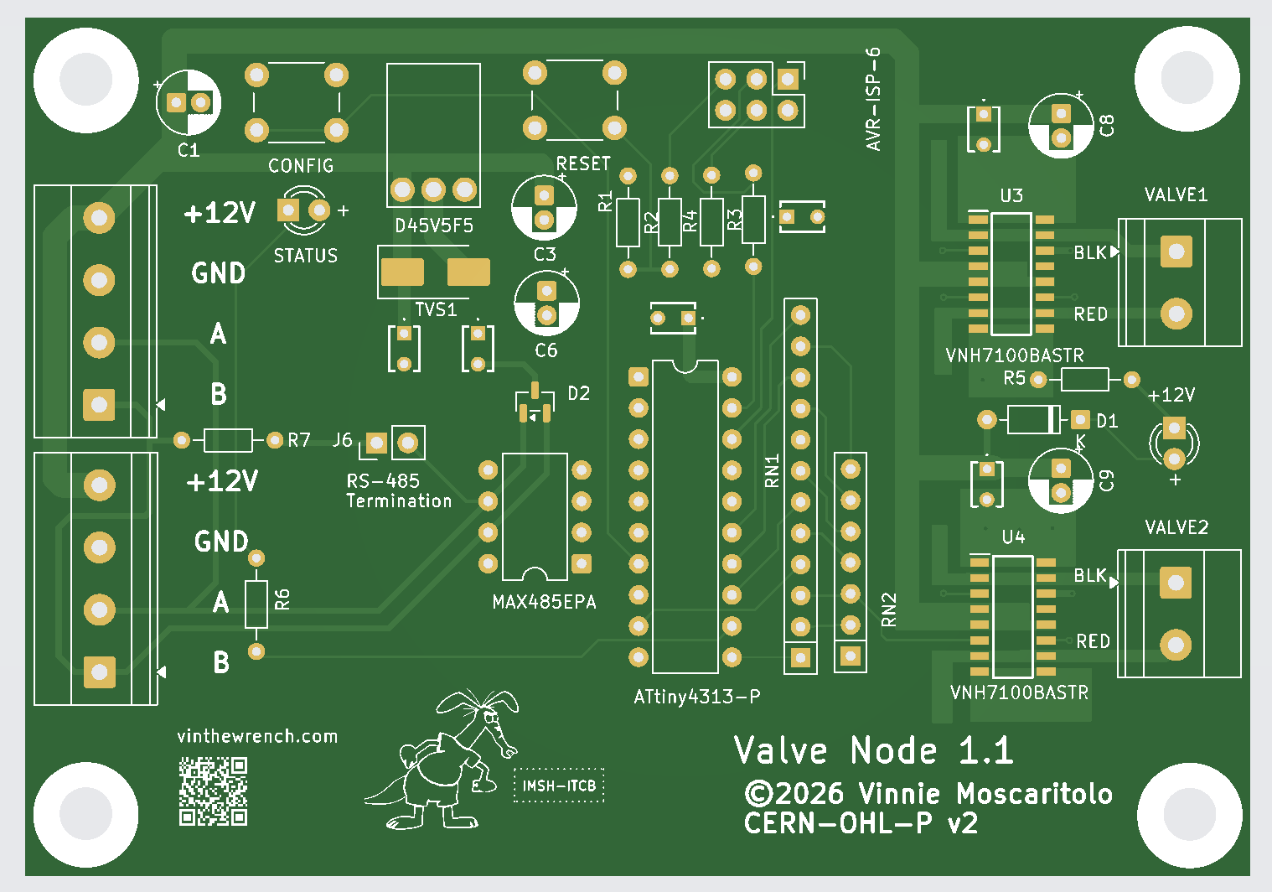
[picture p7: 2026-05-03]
valvenode-slave/hw/1.1/PCB front.png

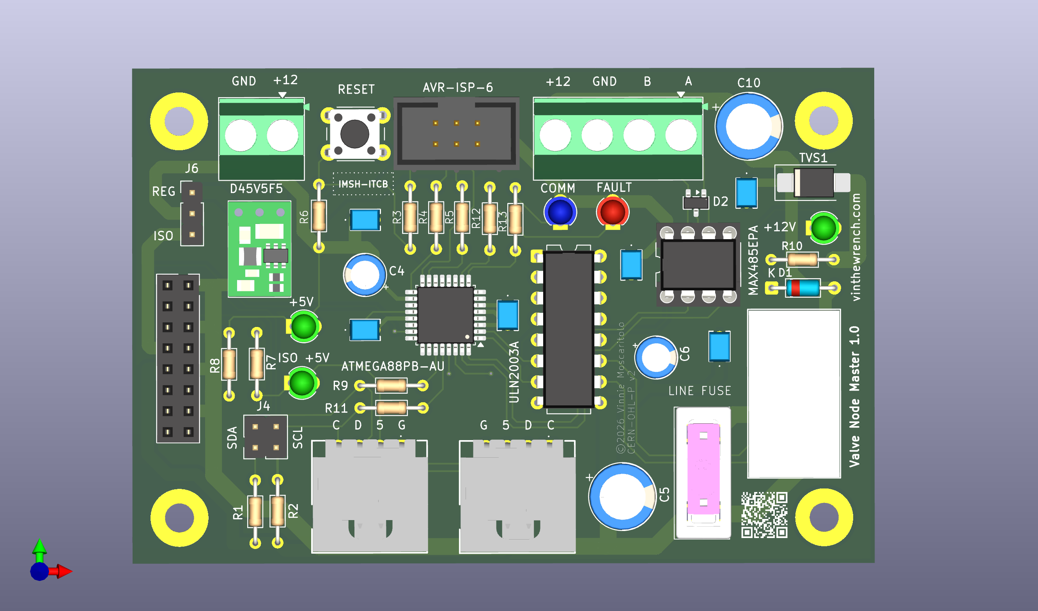
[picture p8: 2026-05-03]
valvenode-master/hw/1.0/valvenode-master.png

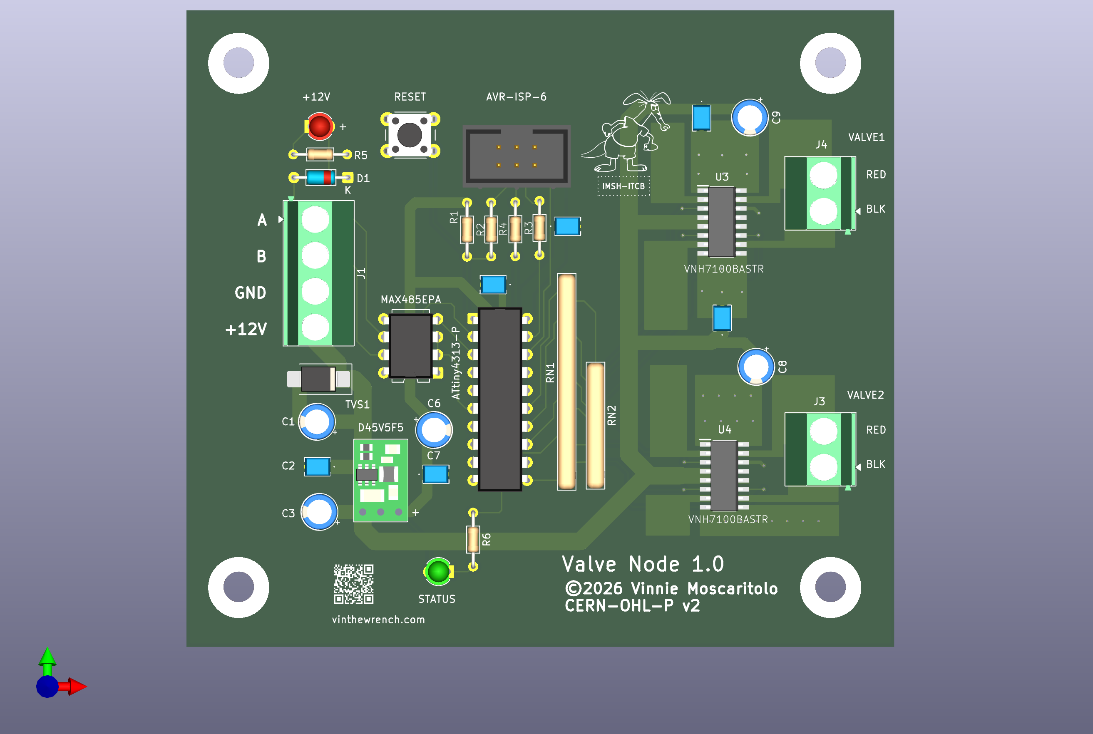
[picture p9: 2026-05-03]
valvenode-slave/hw/1.0/valvenode.png

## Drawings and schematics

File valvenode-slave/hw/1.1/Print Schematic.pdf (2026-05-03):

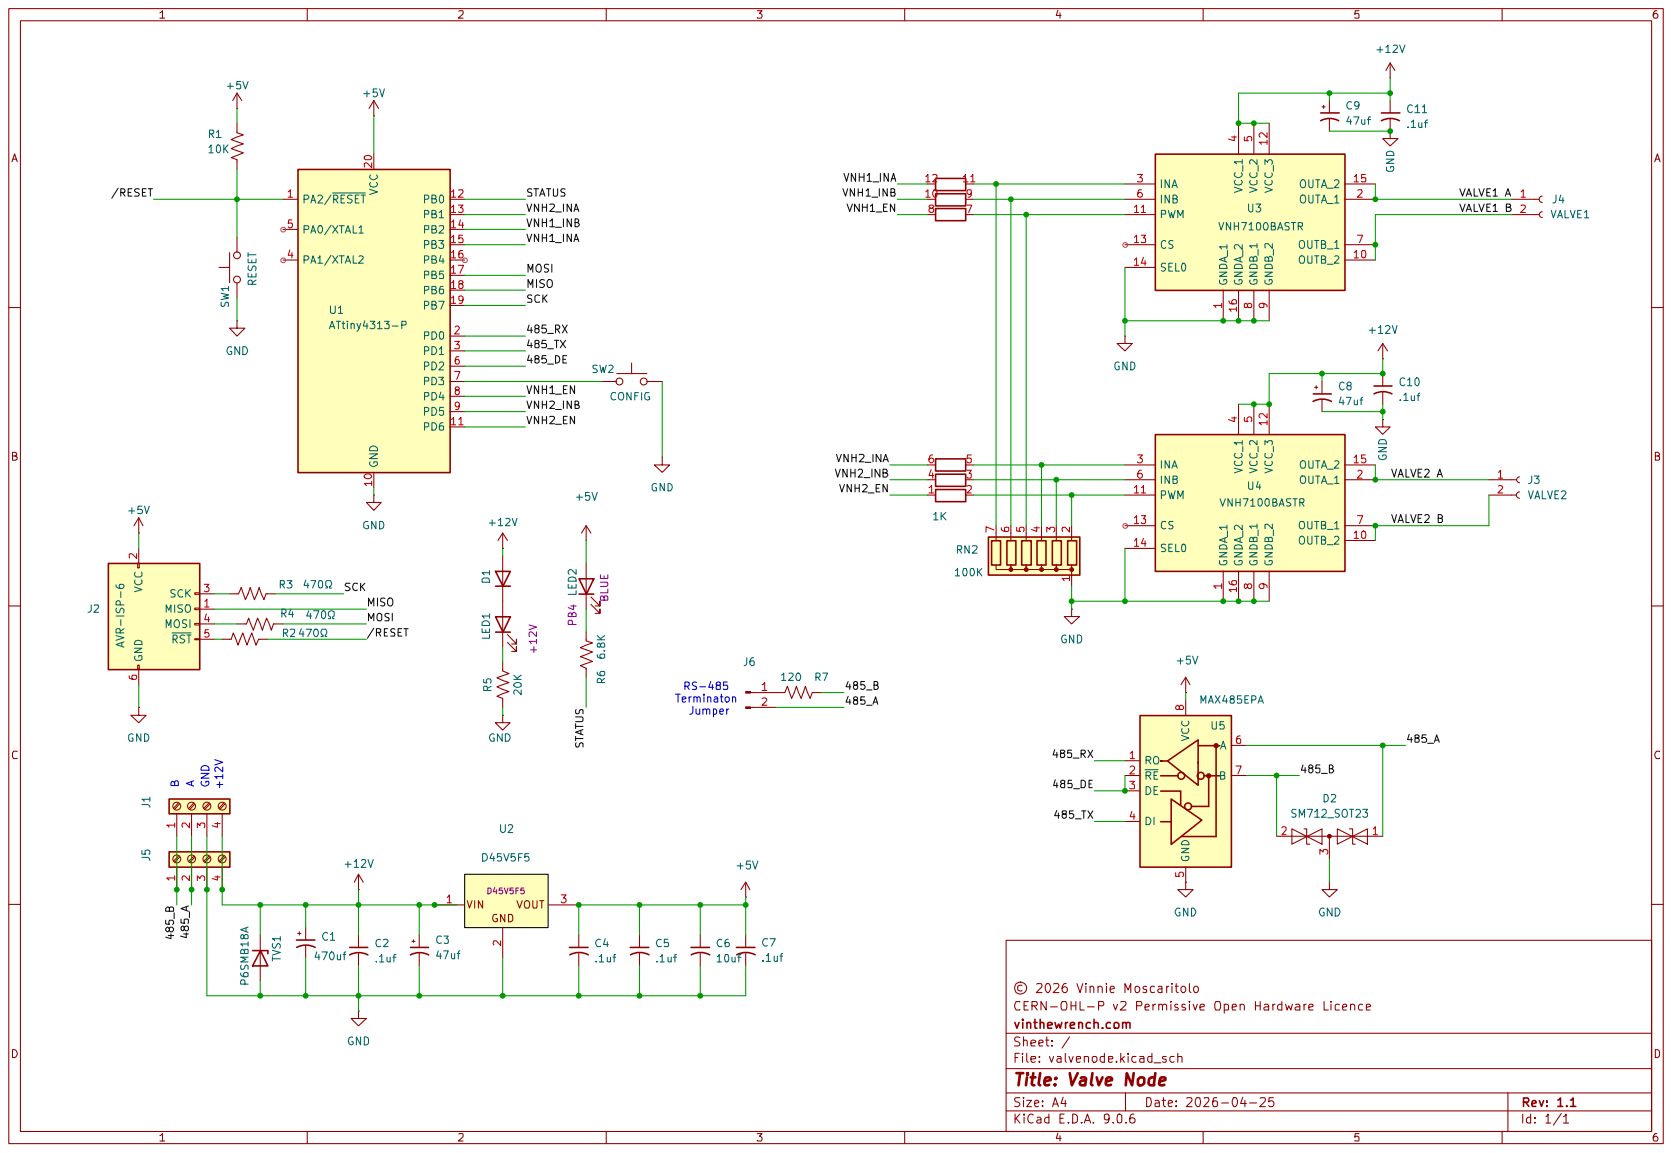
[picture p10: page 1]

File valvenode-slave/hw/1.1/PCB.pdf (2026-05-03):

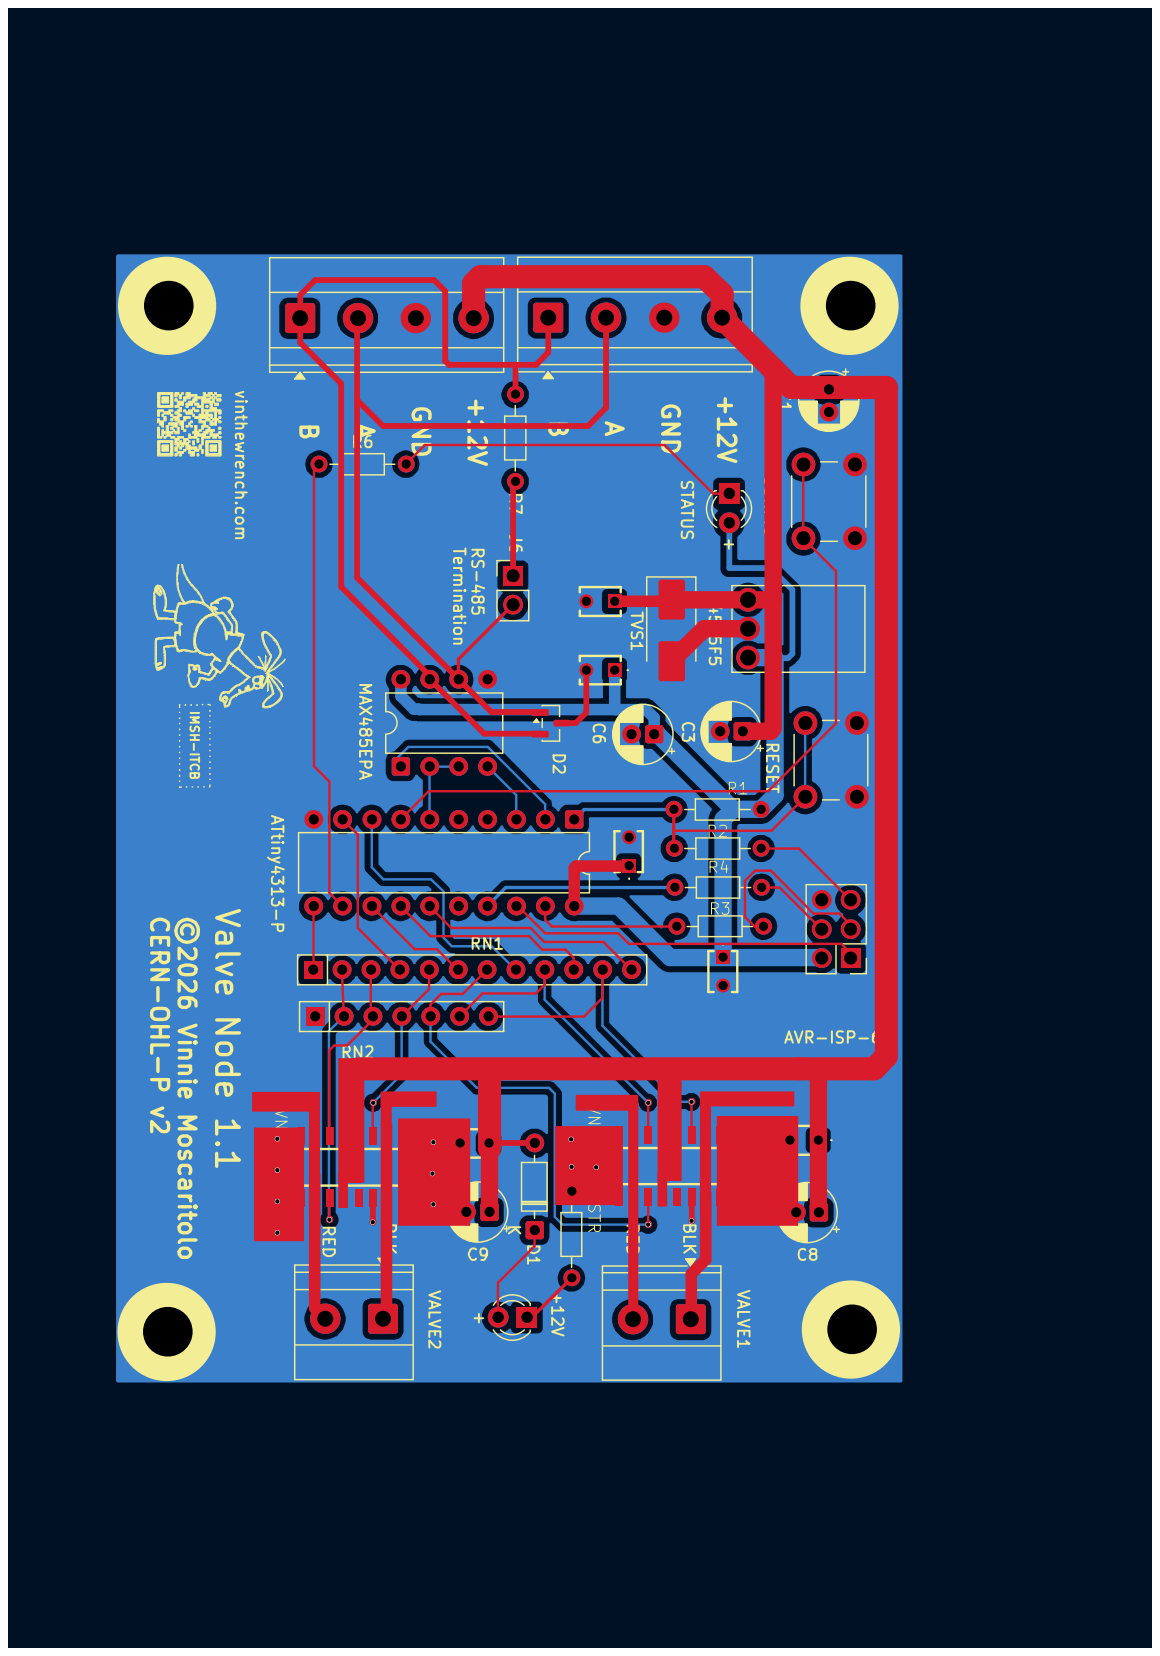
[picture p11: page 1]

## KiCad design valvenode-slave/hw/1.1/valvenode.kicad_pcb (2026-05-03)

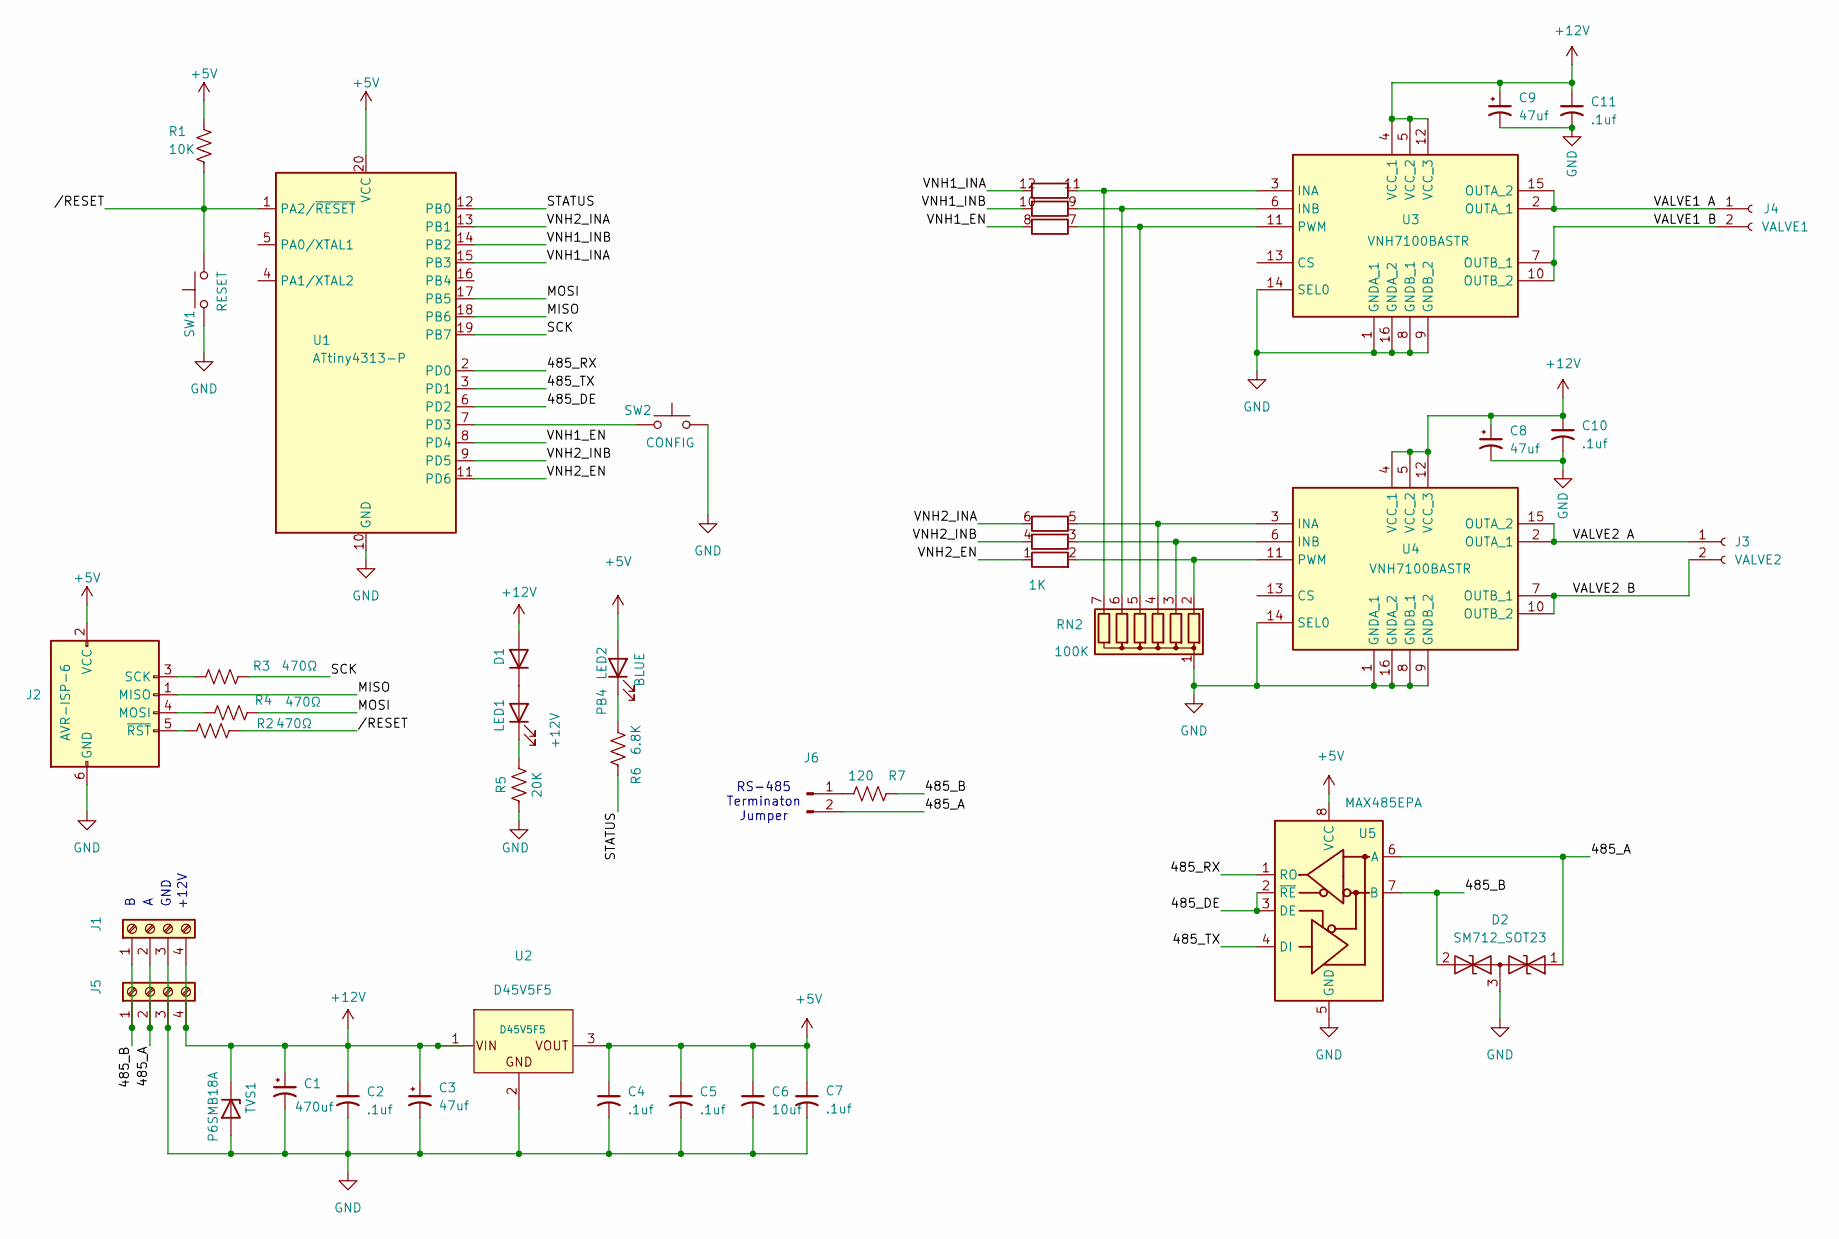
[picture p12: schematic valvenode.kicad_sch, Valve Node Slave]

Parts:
C1: 470uf; CP_Radial_D5.0mm_P2.00mm
C2, C4, C5, C7, C10, C11: .1uf; RCER71H104K0DBH03A
C3, C8, C9: 47uf; CP_Radial_D5.0mm_P2.00mm
C6: 10uf; CP_Radial_D5.0mm_P2.00mm
D1: 1N4148WS; D_DO-35_SOD27_P7.62mm_Horizontal
D2: SM712_SOT23; SOT-23
J1, J5: +12; TerminalBlock_Phoenix_MKDS-1,5-4-5.08_1x04_P5.08mm_Horizont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
J2: AVR-ISP-6; PinHeader_2x03_P2.54mm_Vertical
J3: VALVE2; TerminalBlock_Phoenix_MKDS-1,5-2-5.08_1x02_P5.08mm_Horizont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
J4: VALVE1; TerminalBlock_Phoenix_MKDS-1,5-2-5.08_1x02_P5.08mm_Horizont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
J6: Conn_01x02_Pin; PinHeader_1x02_P2.54mm_Vertical
LED1: 151033GS03000; LED_D3.0mm
LED2: 1510x4BS03000; LED_D3.0mm
R1: 10K; R_Axial_DIN0204_L3.6mm_D1.6mm_P7.62mm_Horizontal
R2, R3, R4: 470Ω; R_Axial_DIN0204_L3.6mm_D1.6mm_P7.62mm_Horizontal
R5: 20K; R_Axial_DIN0204_L3.6mm_D1.6mm_P7.62mm_Horizontal
R6: 6.8K; R_Axial_DIN0204_L3.6mm_D1.6mm_P7.62mm_Horizontal
R7: 120; R_Axial_DIN0204_L3.6mm_D1.6mm_P7.62mm_Horizontal
RN1: 1K; R_Array_SIP12; Manufacturer_Part_Number 4612X-102-102LF
RN2: 100K; R_Array_SIP7; Manufacturer_Part_Number 4607X-101-104LF
SW1: RESET; SW_PUSH_6mm
SW2: CONFIG; SW_PUSH_6mm
TVS1: P6SMB18A; D_SMB_Handsoldering
U1: ATtiny4313-P; DIP-20_W7.62mm
U2: D45V5F5
U3, U4: VNH7100BASTR; SOIC127P600X175-16N; Manufacturer_Part_Number VNH7100BASTR; Mouser Part Number 511-VNH7100BASTR
U5: MAX485EPA; DIP-8_W7.62mm

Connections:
+5V: C4.1, C5.1, C6.1, C7.1, J2.2 (VCC), LED2.2 (A), R1.1, U1.20 (VCC), U2.3 (VOUT), U5.8 (VCC)
+12V: C1.1, C2.1, C3.1, C8.1, C9.1, C10.1, C11.1, D1.2 (A), J1.4, J5.4, TVS1.1 (K), U2.1 (VIN), U3.4 (VCC_1), U3.5 (VCC_2), U3.12 (VCC_3), U4.4 (VCC_1), U4.5 (VCC_2), U4.12 (VCC_3)
/485_A: D2.1 (A1), J1.2, J5.2, J6.2, U5.6 (A)
/485_B: D2.2 (A2), J1.1, J5.1, R7.1, U5.7 (B)
/485_DE: U1.6 (PD2), U5.2 (~RE), U5.3 (DE)
/485_RX: U1.2 (PD0), U5.1 (RO)
/485_TX: U1.3 (PD1), U5.4 (DI)
/MISO: J2.1 (MISO), U1.18 (PB6)
/MOSI: R4.1, U1.17 (PB5)
/SCK: R3.1, U1.19 (PB7)
/STATUS: R6.1, U1.12 (PB0)
/VALVE1 A: J4.1, U3.2 (OUTA_1), U3.15 (OUTA_2)
/VALVE1 B: J4.2, U3.7 (OUTB_1), U3.10 (OUTB_2)
/VALVE2 A: J3.1, U4.2 (OUTA_1), U4.15 (OUTA_2)
/VALVE2 B: J3.2, U4.7 (OUTB_1), U4.10 (OUTB_2)
/VNH1_EN: RN1.8 (R4.2), U1.8 (PD4)
/VNH1_INA: RN1.12 (R6.2), U1.15 (PB3)
/VNH1_INB: RN1.10 (R5.2), U1.14 (PB2)
/VNH2_EN: RN1.1 (R1.1), U1.11 (PD6)
/VNH2_INA: RN1.6 (R3.2), U1.13 (PB1)
/VNH2_INB: RN1.4 (R2.2), U1.9 (PD5)
//RESET: R1.2, R2.1, SW1.2, U1.1 (PA2/~RESET)
GND: C1.2, C2.2, C3.2, C4.2, C5.2, C6.2, C7.2, C8.2, C9.2, C10.2, C11.2, D2.3 (common), J1.3, J2.6 (GND), J5.3, R5.2, RN2.1 (common), SW1.1, SW2.2, TVS1.2 (A), U1.10 (GND), U2.2 (GND), U3.1 (GNDA_1), U3.8 (GNDB_1), U3.9 (GNDB_2), U3.14 (SEL0), U3.16 (GNDA_2), U4.1 (GNDA_1), U4.8 (GNDB_1), U4.9 (GNDB_2), U4.14 (SEL0), U4.16 (GNDA_2), U5.5 (GND)
unnamed: D1.1 (K), LED1.2 (A)
unnamed: J2.4 (MOSI), R4.2
unnamed: J2.3 (SCK), R3.2
unnamed: J2.5 (~RST), R2.2
unnamed: J6.1, R7.2
unnamed: LED1.1 (K), R5.1
unnamed: LED2.1 (K), R6.2
unnamed: RN1.2 (R1.2), RN2.2 (R1), U4.11 (PWM)
unnamed: RN1.3 (R2.1), RN2.3 (R2), U4.6 (INB)
unnamed: RN1.5 (R3.1), RN2.4 (R3), U4.3 (INA)
unnamed: RN1.7 (R4.1), RN2.5 (R4), U3.11 (PWM)
unnamed: RN1.9 (R5.1), RN2.6 (R5), U3.6 (INB)
unnamed: RN1.11 (R6.1), RN2.7 (R6), U3.3 (INA)
unnamed: SW2.1, U1.7 (PD3)

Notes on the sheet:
RS-485 Terminaton Jumper
GND
+12V

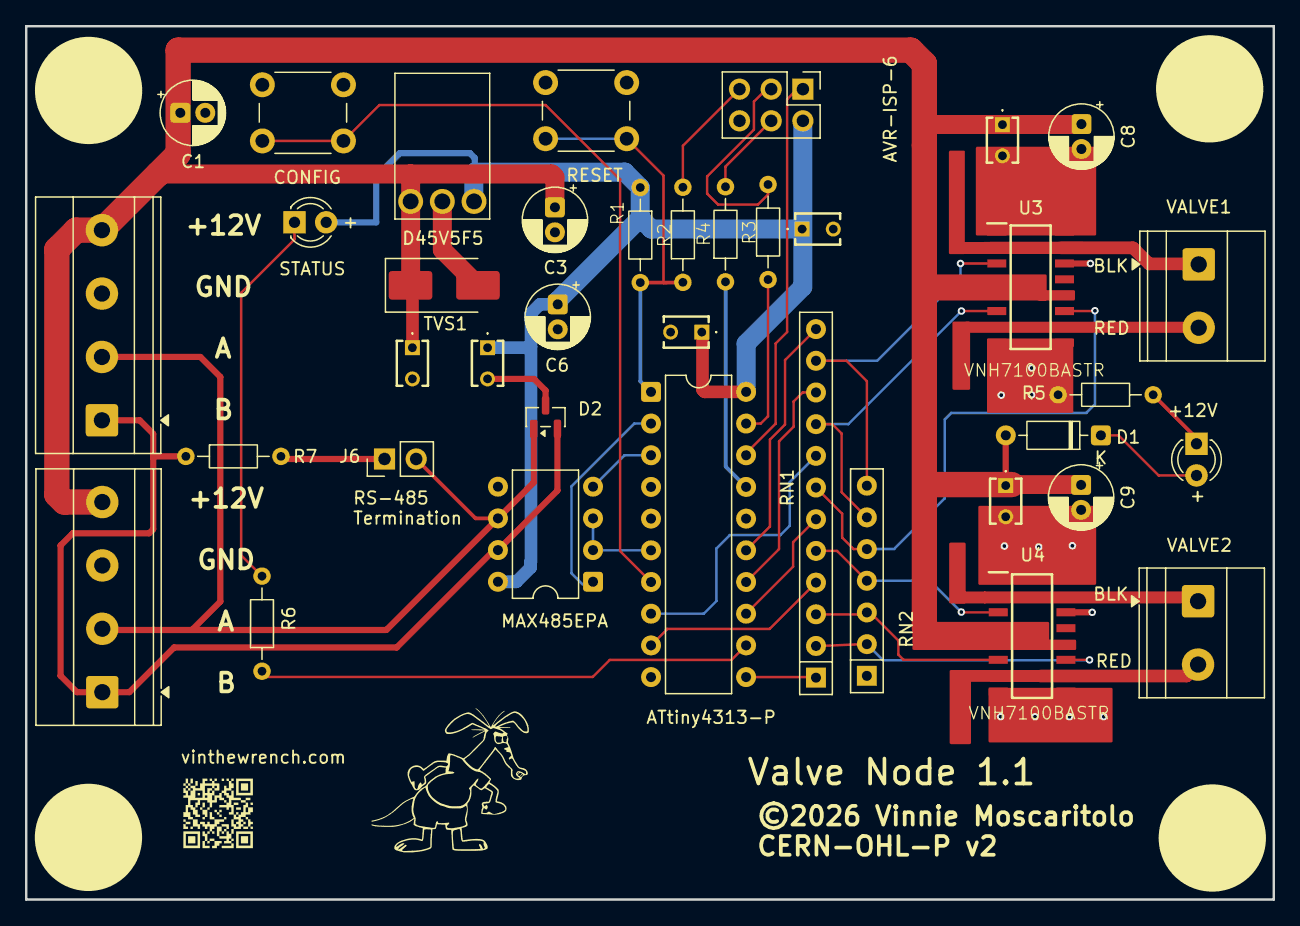
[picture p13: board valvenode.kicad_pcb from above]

Board: 2 copper layers, 100.0 x 70.0 mm, 39 parts (0 on the bottom side), 37 nets.

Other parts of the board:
X: LOGO; aard1

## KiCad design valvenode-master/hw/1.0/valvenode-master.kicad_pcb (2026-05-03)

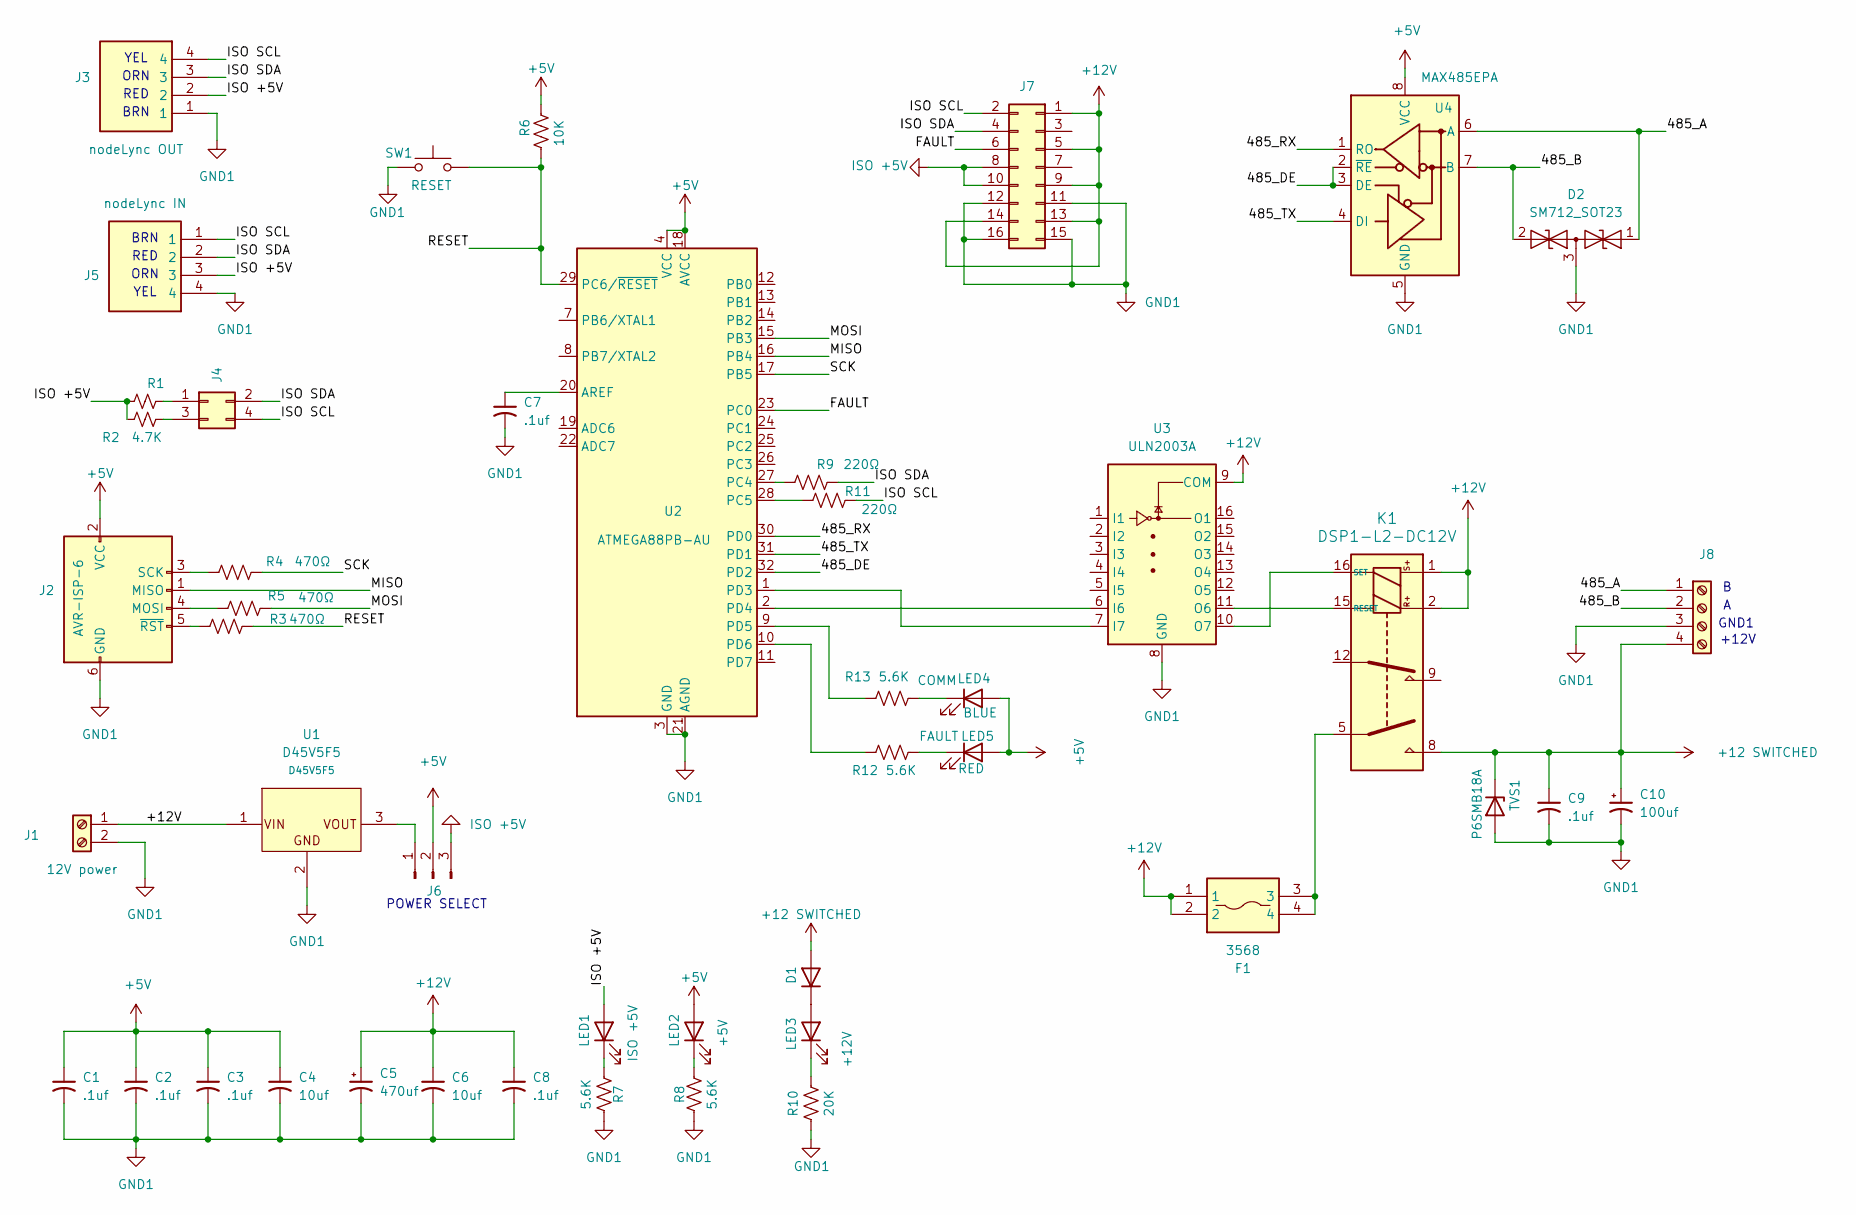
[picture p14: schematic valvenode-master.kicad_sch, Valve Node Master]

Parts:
C1, C2, C3, C7, C8, C9: .1uf; RCER71H104K0DBH03A
C4, C6: 10uf; CP_Radial_D5.0mm_P2.00mm
C5: 470uf; CP_Radial_D8.0mm_P3.50mm
C10: 100uf; CP_Radial_D8.0mm_P3.50mm
D1: 1N4148WS; D_DO-35_SOD27_P7.62mm_Horizontal
D2: SM712_SOT23; SOT-23
F1: 3568; Mouser Part Number 534-3568
J1: 12V power; TerminalBlock_Phoenix_MKDS-1,5-2-5.08_1x02_P5.08mm_Horizont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
J2: AVR-ISP-6; PinHeader_2x03_P2.54mm_Vertical
J3, J5: 70551-0003; 705510003; Manufacturer_Part_Number 70551-0003; Mouser Part Number 538-70551-0003
J4: Conn_02x02_Odd_Even; PinHeader_2x02_P2.54mm_Vertical
J6: Conn_01x03_Pin; PinHeader_1x03_P2.54mm_Vertical
J7: Conn_02x08_Odd_Even; PinSocket_2x08_P2.54mm_Vertical
J8: +12; TerminalBlock_Phoenix_MKDS-1,5-4-5.08_1x04_P5.08mm_Horizont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
K1: DSP1-L2-DC12V
LED1, LED2, LED3: 151033GS03000; LED_D3.0mm
LED4: 151034BS03000; LED_D3.0mm
LED5: 151033RS03000; LED_D3.0mm
R1, R2: 4.7K; R_Axial_DIN0204_L3.6mm_D1.6mm_P7.62mm_Horizontal
R3, R4, R5: 470Ω; R_Axial_DIN0204_L3.6mm_D1.6mm_P7.62mm_Horizontal
R6: 10K; R_Axial_DIN0204_L3.6mm_D1.6mm_P7.62mm_Horizontal
R7, R8, R12, R13: 5.6K; R_Axial_DIN0204_L3.6mm_D1.6mm_P7.62mm_Horizontal
R9, R11: 220Ω; R_Axial_DIN0204_L3.6mm_D1.6mm_P7.62mm_Horizontal
R10: 20K; R_Axial_DIN0204_L3.6mm_D1.6mm_P7.62mm_Horizontal
SW1: RESET; SW_PUSH_6mm
TVS1: P6SMB18A; D_SMB_Handsoldering
U1: D45V5F5
U2: ATMEGA88PB-AU; TQFP-32_7x7mm_P0.8mm
U3: ULN2003A; DIP-16_W7.62mm
U4: MAX485EPA; DIP-8_W7.62mm

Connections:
+5V: C1.1, C2.1, C3.1, C4.1, J2.2 (VCC), J6.2, LED2.2 (A), LED4.2 (A), LED5.2 (A), R6.1, U2.4 (VCC), U2.6 (VCC), U2.18 (AVCC), U4.8 (VCC); also elsewhere on the board
+12 SWITCHED: C9.1, C10.1, D1.2 (A), J8.4, K1.8, TVS1.1 (K)
+12V: C5.1, C6.1, C8.1, F1.1, F1.2, J1.1, J7.1, J7.5, J7.9, J7.13, J7.14, K1.1, K1.2, U1.1 (VIN), U3.9 (COM); also elsewhere on the board
/485_A: D2.1 (A1), J8.1, U4.6 (A)
/485_B: D2.2 (A2), J8.2, U4.7 (B)
/485_DE: U2.32 (PD2), U4.2 (~RE), U4.3 (DE)
/485_RX: U2.30 (PD0), U4.1 (RO)
/485_TX: U2.31 (PD1), U4.4 (DI)
/FAULT: J7.6, U2.23 (PC0)
/ISO SCL: J3.4, J4.4, J5.1, J7.2, R11.1
/ISO SDA: J3.3, J4.2, J5.2, J7.4, R9.1
/MISO: J2.1 (MISO), U2.16 (PB4)
/MOSI: R5.1, U2.15 (PB3)
/RESET: R3.1, R6.2, SW1.2, U2.29 (PC6/~RESET)
/SCK: R4.1, U2.17 (PB5)
GND1: C1.2, C2.2, C3.2, C4.2, C5.2, C6.2, C7.2, C8.2, C9.2, C10.2, D2.3 (common), J1.2, J2.6 (GND), J3.1, J5.4, J7.11, J7.12, J7.15, J7.16, J8.3, R7.2, R8.1, R10.2, SW1.1, TVS1.2 (A), U1.2 (GND), U2.3 (GND), U2.5 (GND), U2.21 (AGND), U3.8 (GND), U4.5 (GND)
ISO +5V: J3.2, J5.3, J6.3, J7.8, J7.10, LED1.2 (A), R1.2, R2.2
unnamed: D1.1 (K), LED3.2 (A)
unnamed 18: F1.3, F1.4, K1.5; also elsewhere on the board
unnamed: J2.4 (MOSI), R5.2
unnamed: J2.3 (SCK), R4.2
unnamed: J2.5 (~RST), R3.2
unnamed: J4.1, R1.1
unnamed: J4.3, R2.1
unnamed: J6.1, U1.3 (VOUT)
unnamed: K1.15 (RESET), U3.11 (O6)
unnamed: K1.16 (SET), U3.10 (O7)
unnamed: LED1.1 (K), R7.1
unnamed: LED2.1 (K), R8.2
unnamed: LED3.1 (K), R10.1
unnamed 30: LED4.1 (K), R13.2; also elsewhere on the board
unnamed 31: LED5.1 (K), R12.2; also elsewhere on the board
unnamed: C7.1, U2.20 (AREF)
unnamed: R9.2, U2.27 (PC4)
unnamed: R11.2, U2.28 (PC5)
unnamed: U2.1 (PD3), U3.7 (I7)
unnamed: U2.2 (PD4), U3.6 (I6)
unnamed: R13.1, U2.9 (PD5)
unnamed: R12.1, U2.10 (PD6)

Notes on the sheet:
GND1
YEL
BRN
ORN
+12V
POWER SELECT
RED

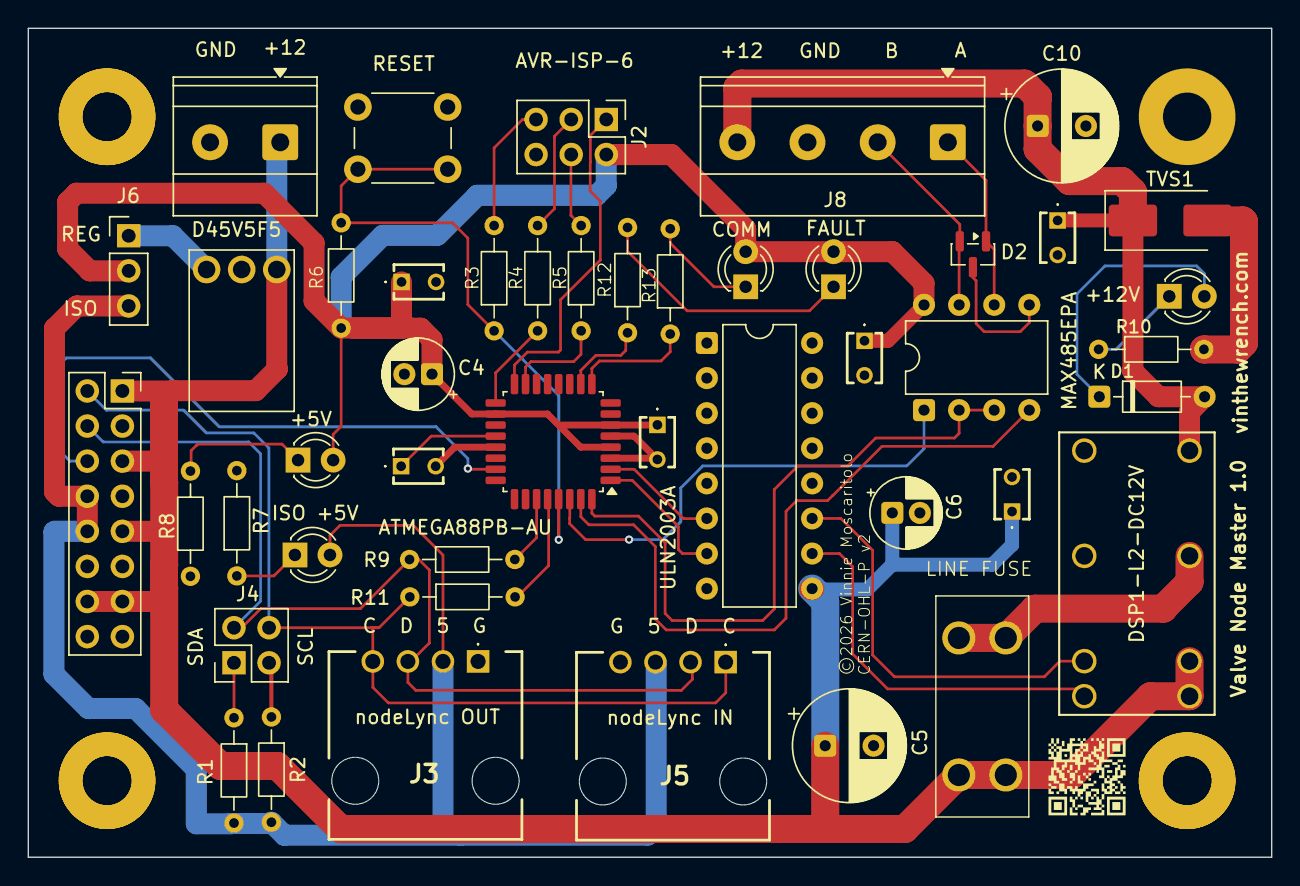
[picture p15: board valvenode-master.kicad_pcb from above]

Board: 2 copper layers, 90.0 x 60.0 mm, 50 parts (0 on the bottom side), 39 nets.

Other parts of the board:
COMM: 151034BS03000; LED_D3.0mm
FAULT: 151033RS03000; LED_D3.0mm
H1, H2, H3, H4: MountingHole_3.5mm_Pad
LINE FUSE: 3568

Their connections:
+5V: COMM.2 (A), FAULT.2 (A); also elsewhere on the board
+12V: LINE FUSE.1, LINE FUSE.2; also elsewhere on the board
unnamed 18: LINE FUSE.3, LINE FUSE.4; also elsewhere on the board
unnamed 30: COMM.1 (K); also elsewhere on the board
unnamed 31: FAULT.1 (K); also elsewhere on the board

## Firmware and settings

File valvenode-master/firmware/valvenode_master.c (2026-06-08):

/**
 * @file valvenode_master.c
 * @brief Real Valve Master firmware for ATmega88PB.
 *
 * This firmware implements the production valve-master architecture:
 *
 *   Host over I2C
 *     -> ATmega88PB Valve Master
 *       -> switched 12 V field bus
 *       -> half-duplex RS-485
 *       -> valve-node slaves
 *
 * The I2C register map, command values, result values, reply registers, and
 * command deferral model intentionally match valvenode_master_sim.c. The sim
 * firmware is the bench model. This file is the real hardware backend.
 *
 * Target:
 *   ATmega88PB-AU @ 8 MHz
 *
 * I2C:
 *   7-bit address passed by Makefile using -DI2C_ADDR=0x09.
 *   Defaults to 0x09 if not supplied.
 *
 * RS-485 valve-node protocol:
 *   Requests: :DDC[A]KK\r
 *   Replies:  :DDC[A...][KK]\r or :DDC[A...][KK]\n
 *
 * Request checksums are now always sent. Reply checksums are verified.
 *
 * Locked product MCU pin assignments:
 *   PB3  MOSI
 *   PB4  MISO
 *   PB5  SCK
 *   PC0  FAULT_OUT, open-drain style: normal = high-Z, fault = driven low
 *   PC4  SDA
 *   PC5  SCL
 *   PD0  485RX
 *   PD1  485TX
 *   PD2  485DE
 *   PD3  RELAY_SET
 *   PD4  RELAY_RESET
 *   PD5  BLUE_LED_COMM
 *   PD6  RED_LED_FAULT
 */

#ifndef F_CPU
#define F_CPU 8000000UL
#endif

#include <avr/io.h>
#include <avr/interrupt.h>
#include <util/delay.h>
#include <util/twi.h>
#include <stdbool.h>
#include <stdint.h>

/* ============================================================================
 * Build configuration
 * ========================================================================== */

/** @brief 7-bit I2C slave address. Usually supplied by Makefile. */
#ifndef I2C_ADDR
#define I2C_ADDR                    0x09u
#endif

/** @brief Master firmware version high byte. */
#define MASTER_VERSION_HI           0x01u

/** @brief Master firmware version low byte. */
#define MASTER_VERSION_LO           0x06u

/** @brief Highest valid assigned valve-node address. */
#define MAX_NODE_ADDR               254u

/** @brief Highest channel number accepted by the master API. */
#define MAX_CHANNEL_API             16u

/** @brief Maximum node-map entries exposed in the register file. */
#define NODE_MAP_MAX                32u

/* ============================================================================
 * Product hardware pin map
 * ========================================================================== */

#define FAULT_OUT_PIN               PC0
#define RS485_DE_PIN                PD2
#define RELAY_SET_PIN               PD3
#define RELAY_RESET_PIN             PD4
#define COMM_LED_PIN                PD5
#define FAULT_LED_PIN               PD6

/* ============================================================================
 * Timing
 * ========================================================================== */

#define RELAY_PULSE_MS              30u
#define BUS_POWER_UP_DELAY_MS       250u
#define BAUD                        9600UL
#define UBRR_VALUE                  ((F_CPU / (16UL * BAUD)) - 1UL)
#define RS485_RX_TO_TX_TURNAROUND_MS 2u
#define RS485_NORMAL_TIMEOUT_MS       1000u
#define RS485_WHO_TIMEOUT_MS          6000u
#define RS485_CANCEL_GRACE_MS         20u
#define RS485_CLOSE_ALL_GRACE_MS      100u
#define RX_LINE_MAX                 24u
#define RS485_RETRY_COUNT             1u
#define RS485_RETRY_DELAY_MS          100u

/* ============================================================================
 * I2C register map
 * ========================================================================== */

#define REG_COMMAND                 0x00u
#define REG_STATUS                  0x01u
#define REG_ARG0                    0x02u
#define REG_ARG1                    0x03u
#define REG_ARG2                    0x04u
#define REG_RESULT                  0x05u
#define REG_POWER_STATE             0x06u
#define REG_NODE_COUNT              0x07u
#define REG_REPLY_NODE              0x08u
#define REG_REPLY_CMD               0x09u
#define REG_REPLY_ARG0              0x0Au
#define REG_REPLY_ARG1              0x0Bu
#define REG_VERSION_HI              0x10u
#define REG_VERSION_LO              0x11u
#define REG_NODE_MAP_BASE           0x20u

/* ============================================================================
 * Command values
 * ========================================================================== */

#define CMD_NONE                    0x00u
#define CMD_POWER_ON                0x01u
#define CMD_POWER_OFF               0x02u
#define CMD_WHO                     0x03u
#define CMD_PING                    0x04u
#define CMD_SET_CHANNEL             0x05u
#define CMD_GET_CHANNEL_STATUS      0x06u
#define CMD_GET_NODE_VERSION        0x07u
#define CMD_IDENTIFY                0x08u
#define CMD_CANCEL                  0x09u
#define CMD_CONFIG                  0x0Au
#define CMD_ASSIGN                  0x0Bu
#define CMD_CLEAR_ERROR             0x0Cu
#define CMD_SET_ERROR               0x0Du
#define CMD_CLOSE_ALL               0x0Fu

/* ============================================================================
 * Status and result values
 * ========================================================================== */

#define STATUS_BUSY                 (1u << 0)
#define STATUS_ERROR                (1u << 1)
#define STATUS_POWER_ON             (1u << 2)

#define RESULT_OK                   0x00u
#define RESULT_BAD_COMMAND          0x01u
#define RESULT_BAD_NODE             0x02u
#define RESULT_BAD_CHANNEL          0x03u
#define RESULT_NODE_NOT_FOUND       0x04u
#define RESULT_UNSUPPORTED_CHANNEL  0x05u
#define RESULT_CONFIG_REQUIRED      0x06u
#define RESULT_ADDRESS_IN_USE       0x07u
#define RESULT_BUSY                 0x08u
#define RESULT_RS485_TIMEOUT        0x09u
#define RESULT_RS485_BAD_CHECKSUM   0x0Au
#define RESULT_RS485_BAD_REPLY      0x0Bu
#define RESULT_RESERVED_0C          0x0Cu
#define RESULT_POWER_OFF            0x0Eu

/* ============================================================================
 * Global state
 * ========================================================================== */

static volatile uint8_t g_regs[256];
static volatile uint8_t g_reg_ptr = 0u;
static volatile bool g_have_reg_ptr = false;
static volatile uint8_t g_pending_cmd = CMD_NONE;
static volatile bool g_cmd_pending = false;
static volatile bool g_i2c_reinit_pending = false;

static char g_rx_line[RX_LINE_MAX];

/* ============================================================================
 * GPIO helpers
 * ========================================================================== */

static inline void comm_led_on(void)
{
    PORTD &= (uint8_t)~(1u << COMM_LED_PIN);
}

static inline void comm_led_off(void)
{
    PORTD |= (1u << COMM_LED_PIN);
}

static inline void fault_led_on(void)
{
    PORTD &= (uint8_t)~(1u << FAULT_LED_PIN);
}

static inline void fault_led_off(void)
{
    PORTD |= (1u << FAULT_LED_PIN);
}

static inline void fault_out_release(void)
{
    PORTC &= (uint8_t)~(1u << FAULT_OUT_PIN);
    DDRC  &= (uint8_t)~(1u << FAULT_OUT_PIN);
}

static inline void fault_out_assert(void)
{
    PORTC &= (uint8_t)~(1u << FAULT_OUT_PIN);
    DDRC  |= (1u << FAULT_OUT_PIN);
}

static void update_fault_outputs(void)
{
    if (g_regs[REG_STATUS] & STATUS_ERROR) {
        fault_led_on();
        fault_out_assert();
    } else {
        fault_led_off();
        fault_out_release();
    }
}

static inline void rs485_set_rx(void)
{
    PORTD &= (uint8_t)~(1u << RS485_DE_PIN);
}

static inline void rs485_set_tx(void)
{
    PORTD |= (1u << RS485_DE_PIN);
}

static void gpio_init(void)
{
    fault_out_release();

    PORTD &= (uint8_t)~(1u << RS485_DE_PIN);
    PORTD &= (uint8_t)~(1u << RELAY_SET_PIN);
    PORTD &= (uint8_t)~(1u << RELAY_RESET_PIN);
    PORTD |= (1u << COMM_LED_PIN);
    PORTD |= (1u << FAULT_LED_PIN);

    DDRD |= (1u << RS485_DE_PIN) |
            (1u << RELAY_SET_PIN) |
            (1u << RELAY_RESET_PIN) |
            (1u << COMM_LED_PIN) |
            (1u << FAULT_LED_PIN);

    rs485_set_rx();
    comm_led_off();
    fault_led_off();
}

/* ============================================================================
 * Result / register helpers
 * ========================================================================== */

static void set_result(uint8_t result)
{
    g_regs[REG_RESULT] = result;

    if (result == RESULT_OK) {
        g_regs[REG_STATUS] &= (uint8_t)~STATUS_ERROR;
    } else {
        g_regs[REG_STATUS] |= STATUS_ERROR;
    }

    update_fault_outputs();
}

static bool field_power_is_on(void)
{
    return (g_regs[REG_STATUS] & STATUS_POWER_ON) != 0u;
}

static bool require_field_power(void)
{
    if (!field_power_is_on()) {
        set_result(RESULT_POWER_OFF);
        return false;
    }

    return true;
}

static void clear_reply_regs(void)
{
    g_regs[REG_REPLY_NODE] = 0u;
    g_regs[REG_REPLY_CMD] = 0u;
    g_regs[REG_REPLY_ARG0] = 0u;
    g_regs[REG_REPLY_ARG1] = 0u;
}

static void clear_node_map(void)
{
    for (uint8_t i = 0u; i < NODE_MAP_MAX; i++) {
        g_regs[REG_NODE_MAP_BASE + i] = 0u;
    }

    g_regs[REG_NODE_COUNT] = 0u;
}

static bool valid_node_addr(uint8_t node)
{
    return (node >= 1u) && (node <= MAX_NODE_ADDR);
}

static bool valid_channel(uint8_t channel)
{
    return (channel >= 1u) && (channel <= MAX_CHANNEL_API);
}

/* ============================================================================
 * Relay / field power
 * ========================================================================== */

static void relay_drive_off(void)
{
    PORTD &= (uint8_t)~(1u << RELAY_SET_PIN);
    PORTD &= (uint8_t)~(1u << RELAY_RESET_PIN);
}

static void relay_pulse_set(void)
{
    PORTD |= (1u << RELAY_SET_PIN);

    for (uint8_t i = 0u; i < RELAY_PULSE_MS; i++) {
        _delay_ms(1);
    }

    PORTD &= (uint8_t)~(1u << RELAY_SET_PIN);
}

static void relay_pulse_reset(void)
{
    PORTD |= (1u << RELAY_RESET_PIN);

    for (uint8_t i = 0u; i < RELAY_PULSE_MS; i++) {
        _delay_ms(1);
    }

    PORTD &= (uint8_t)~(1u << RELAY_RESET_PIN);
}

static void bus_power_on(void)
{
    relay_pulse_set();

    g_regs[REG_POWER_STATE] = 1u;
    g_regs[REG_STATUS] |= STATUS_POWER_ON;

    for (uint16_t i = 0u; i < BUS_POWER_UP_DELAY_MS; i++) {
        _delay_ms(1);
    }
}

static void bus_power_off(void)
{
    relay_pulse_reset();

    g_regs[REG_POWER_STATE] = 0u;
    g_regs[REG_STATUS] &= (uint8_t)~STATUS_POWER_ON;
}

/* ============================================================================
 * UART / RS-485 low level
 * ========================================================================== */

static void uart_init(void)
{
    UBRR0H = (uint8_t)(UBRR_VALUE >> 8);
    UBRR0L = (uint8_t)(UBRR_VALUE & 0xFFu);

    UCSR0A = 0u;
    UCSR0B = (1u << RXEN0) | (1u << TXEN0);
    UCSR0C = (1u << UCSZ01) | (1u << UCSZ00);

    rs485_set_rx();
}

static void uart_putc(char c)
{
    while ((UCSR0A & (1u << UDRE0)) == 0u) {
    }

    UDR0 = (uint8_t)c;
}

static bool uart_getc_nonblocking(char *out)
{
    if (UCSR0A & (1u << RXC0)) {
        *out = (char)UDR0;
        return true;
    }

    return false;
}

static void uart_flush_rx(void)
{
    char c;

    while (uart_getc_nonblocking(&c)) {
    }
}

static void rs485_wait_rx_to_tx_turnaround(void)
{
    for (uint8_t i = 0u; i < RS485_RX_TO_TX_TURNAROUND_MS; i++) {
        _delay_ms(1);
    }
}

static void uart_write_frame(const char *s)
{
    rs485_wait_rx_to_tx_turnaround();
    uart_flush_rx();

    rs485_set_tx();
    comm_led_on();

    UCSR0A |= (1u << TXC0);

    while (*s != '\0') {
        uart_putc(*s++);
    }

    while ((UCSR0A & (1u << TXC0)) == 0u) {
    }

    rs485_set_rx();
    comm_led_off();
}

/* ============================================================================
 * Protocol utilities
 * ========================================================================== */

static char nibble_to_hex(uint8_t v)
{
    v &= 0x0Fu;

    if (v < 10u) {
        return (char)('0' + v);
    }

    return (char)('A' + (v - 10u));
}

static int8_t hex_value(char c)
{
    if ((c >= '0') && (c <= '9')) {
        return (int8_t)(c - '0');
    }

    if ((c >= 'A') && (c <= 'F')) {
        return (int8_t)(10 + (c - 'A'));
    }

    if ((c >= 'a') && (c <= 'f')) {
        return (int8_t)(10 + (c - 'a'));
    }

    return -1;
}

static bool parse_hex_byte(const char *s, uint8_t *out)
{
    int8_t hi = hex_value(s[0]);
    int8_t lo = hex_value(s[1]);

    if ((hi < 0) || (lo < 0)) {
        return false;
    }

    *out = (uint8_t)(((uint8_t)hi << 4) | (uint8_t)lo);
    return true;
}

static uint8_t ascii_sum_checksum(const char *body, uint8_t len)
{
    uint8_t sum = 0u;

    for (uint8_t i = 0u; i < len; i++) {
        sum = (uint8_t)(sum + (uint8_t)body[i]);
    }

    return sum;
}

static bool channel_to_wire_char(uint8_t channel, char *out)
{
    if (!valid_channel(channel)) {
        return false;
    }

    if (channel <= 9u) {
        *out = (char)('0' + channel);
    } else if (channel <= 15u) {
        *out = (char)('A' + (channel - 10u));
    } else {
        *out = '0';
    }

    return true;
}

static bool wire_char_to_channel(char c, uint8_t *channel)
{
    if ((c >= '1') && (c <= '9')) {
        *channel = (uint8_t)(c - '0');
        return true;
    }

    if ((c >= 'A') && (c <= 'F')) {
        *channel = (uint8_t)(10u + (uint8_t)(c - 'A'));
        return true;
    }

    if ((c >= 'a') && (c <= 'f')) {
        *channel = (uint8_t)(10u + (uint8_t)(c - 'a'));
        return true;
    }

    if (c == '0') {
        *channel = 16u;
        return true;
    }

    return false;
}

/**
 * @brief Build a checksummed valve-node request frame.
 *
 * Request body is:
 *   DD C [A]
 *
 * Checksum is the 8-bit ASCII sum of the body bytes only. The leading ':' and
 * trailing CR are not included.
 *
 * No-argument frame:
 *   :DDCKK\r
 *
 * Argument frame:
 *   :DDCAKK\r
 */
static void make_request(uint8_t node, char cmd, char arg, char *frame, uint8_t frame_len)
{
    char body[5];
    uint8_t body_len = 0u;
    uint8_t cs = 0u;
    uint8_t pos = 0u;

    if (frame_len == 0u) {
        return;
    }

    frame[0] = '\0';

    body[body_len++] = nibble_to_hex((uint8_t)(node >> 4));
    body[body_len++] = nibble_to_hex(node);
    body[body_len++] = cmd;

    if (arg != 0) {
        body[body_len++] = arg;
    }

    /*
     * Need:
     *   ':' + body + 2 checksum chars + '\r' + '\0'
     *
     * body_len is 3 or 4, so required length is 8 or 9.
     */
    if (frame_len < (uint8_t)(body_len + 5u)) {
        return;
    }

    cs = ascii_sum_checksum(body, body_len);

    frame[pos++] = ':';

    for (uint8_t i = 0u; i < body_len; i++) {
        frame[pos++] = body[i];
    }

    frame[pos++] = nibble_to_hex((uint8_t)(cs >> 4));
    frame[pos++] = nibble_to_hex(cs);
    frame[pos++] = '\r';
    frame[pos] = '\0';
}

/* ============================================================================
 * RS-485 receive / parse
 * ========================================================================== */

static bool read_line_timeout(uint16_t timeout_ms)
{
    bool active = false;
    uint8_t len = 0u;

    for (uint16_t elapsed = 0u; elapsed < timeout_ms; elapsed++) {
        char c;

        while (uart_getc_nonblocking(&c)) {
            if (!active) {
                if (c == ':') {
                    active = true;
                    len = 0u;
                    g_rx_line[len++] = ':';
                }
                continue;
            }

            if ((c == '\r') || (c == '\n')) {
                if (len > 0u) {
                    g_rx_line[len] = '\0';
                    return true;
                }

                active = false;
                len = 0u;
                continue;
            }

            if (c == ':') {
                active = true;
                len = 0u;
                g_rx_line[len++] = ':';
                continue;
            }

            if (len < (RX_LINE_MAX - 1u)) {
                g_rx_line[len++] = c;
            } else {
                active = false;
                len = 0u;
            }
        }

        _delay_ms(1);
    }

    return false;
}

static bool parse_reply_line(uint8_t *node, char *cmd, char *arg0, char *arg1)
{
    uint8_t line_len = 0u;
    uint8_t got_cs = 0u;
    uint8_t calc_cs = 0u;
    uint8_t body_len = 0u;

    while ((line_len < RX_LINE_MAX) && (g_rx_line[line_len] != '\0')) {
        line_len++;
    }

    if (line_len < 5u) {
        return false;
    }

    if (g_rx_line[0] != ':') {
        return false;
    }

    if (!parse_hex_byte(&g_rx_line[1], node)) {
        return false;
    }

    if (!parse_hex_byte(&g_rx_line[line_len - 2u], &got_cs)) {
        return false;
    }

    body_len = (uint8_t)(line_len - 3u);
    calc_cs = ascii_sum_checksum(&g_rx_line[1], body_len);

    if (calc_cs != got_cs) {
        set_result(RESULT_RS485_BAD_CHECKSUM);
        return false;
    }

    *cmd = g_rx_line[3];
    *arg0 = 0;
    *arg1 = 0;

    if (line_len > 6u) {
        *arg0 = g_rx_line[4];
    }

    if (line_len > 7u) {
        *arg1 = g_rx_line[5];
    }

    return true;
}

static bool wait_for_reply(uint16_t timeout_ms,
                           uint8_t expected_node,
                           char expected_cmd,
                           uint8_t *reply_node,
                           char *reply_cmd,
                           char *reply_arg0,
                           char *reply_arg1)
{
    uint8_t node = 0u;
    char cmd = 0;
    char arg0 = 0;
    char arg1 = 0;

    while (read_line_timeout(timeout_ms)) {
        if (!parse_reply_line(&node, &cmd, &arg0, &arg1)) {
            if (g_regs[REG_RESULT] != RESULT_RS485_BAD_CHECKSUM) {
                set_result(RESULT_RS485_BAD_REPLY);
            }

            return false;
        }

        if ((expected_node != 0u) && (node != expected_node)) {
            continue;
        }

        if ((expected_cmd != 0) && (cmd != expected_cmd)) {
            continue;
        }

        *reply_node = node;
        *reply_cmd = cmd;
        *reply_arg0 = arg0;
        *reply_arg1 = arg1;

        return true;
    }

    set_result(RESULT_RS485_TIMEOUT);
    return false;
}

static bool send_request_wait_reply(uint8_t node,
                                    char cmd,
                                    char arg,
                                    uint16_t timeout_ms,
                                    uint8_t *reply_node,
                                    char *reply_cmd,
                                    char *reply_arg0,
                                    char *reply_arg1)
{
    char frame[12];

    make_request(node, cmd, arg, frame, sizeof(frame));

    if (frame[0] == '\0') {
        set_result(RESULT_RS485_BAD_REPLY);
        return false;
    }

    for (uint8_t attempt = 0u; attempt <= RS485_RETRY_COUNT; attempt++) {
        uart_flush_rx();
        clear_reply_regs();

        uart_write_frame(frame);

        if (wait_for_reply(timeout_ms,
                           node,
                           0,
                           reply_node,
                           reply_cmd,
                           reply_arg0,
                           reply_arg1)) {
            return true;
        }

        if (g_regs[REG_RESULT] != RESULT_RS485_TIMEOUT) {
            return false;
        }

        if (attempt < RS485_RETRY_COUNT) {
            for (uint8_t i = 0u; i < RS485_RETRY_DELAY_MS; i++) {
                _delay_ms(1);
            }
        }
    }

    return false;
}

/* ============================================================================
 * Command backend
 * ========================================================================== */

static void cmd_power_on(void)
{
    bus_power_on();
    set_result(RESULT_OK);
}

static void cmd_power_off(void)
{
    for (uint8_t i = 0u; i < RS485_CANCEL_GRACE_MS; i++) {
        _delay_ms(1);
    }

    bus_power_off();
    set_result(RESULT_OK);
}
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
int main(void)
{
    gpio_init();
    regs_init();
    uart_init();

    /*
     * Safe idle outputs.
     *
     * Do not call bus_power_off() here. That function pulses the latching
     * relay RESET coil. During firmware/debug cycles, reset should not
     * repeatedly fire relay coils.
     */
    relay_drive_off();

    g_regs[REG_POWER_STATE] = 0u;
    g_regs[REG_STATUS] &= (uint8_t)~STATUS_POWER_ON;
    g_regs[REG_STATUS] &= (uint8_t)~STATUS_BUSY;
    g_regs[REG_STATUS] &= (uint8_t)~STATUS_ERROR;
    g_regs[REG_RESULT] = RESULT_OK;
    update_fault_outputs();

    /*
     * Initialize I2C after the register file is in its final boot state,
     * because i2c_init() preloads TWDR from g_regs.
     */
    i2c_init();

    sei();

    for (;;) {
        if (g_i2c_reinit_pending) {
            cli();
            i2c_init();
            sei();
        }

        if (g_cmd_pending) {
            uint8_t cmd;

            cli();
            cmd = g_pending_cmd;
            g_pending_cmd = CMD_NONE;
            g_cmd_pending = false;
            sei();

            execute_command(cmd);
        }

        update_fault_outputs();
    }
}

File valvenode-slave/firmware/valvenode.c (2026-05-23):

/**
 * @file valvenode.c
 * @brief Dual-valve RS-485 slave node firmware.
 *
 * This firmware implements a compact command/response protocol for a two-channel
 * valve node. The node receives framed ASCII commands over a half-duplex
 * RS-485 link, executes valve operations, reports status, supports address
 * assignment, firmware version query, identify mode, and config mode, and
 * stores its assigned node address in EEPROM.
 *
 * Protocol summary
 * ----------------
 *
 * Request format:
 *   :DDC[A]KK<EOL>
 *
 * Reply format:
 *   :DDC[A][B]KK<EOL>
 *
 * Field meanings:
 *   - ':'  start of frame
 *   - DD   2 hex digit node address
 *   - C    1 character command
 *   - A    optional 1 character argument
 *   - B    optional 1 character second argument in replies
 *   - KK   2 hex digit checksum on requests when REQUIRE_RX_CHECKSUM is enabled
 *          optional only when REQUIRE_RX_CHECKSUM is disabled
 *          required 2 hex digit checksum on replies
 *   - EOL  CR, LF, or CRLF
 *
 * Addressing:
 *   - 01..FE valid node addresses
 *   - FF     broadcast address
 *   - 00     invalid / unassigned address
 *
 * Correct checksummed request examples:
 *   - :04PB4   ping node 04
 *   - :04O1E4  open valve 1 on node 04
 *   - :04C1D8  close valve 1 on node 04
 *   - :04O2E5  open valve 2 on node 04
 *   - :04C2D9  close valve 2 on node 04
 *   - :04S1E8  status valve 1 on node 04
 *   - :04S2E9  status valve 2 on node 04
 *   - :04VBA   get firmware version from node 04
 *   - :04IAD   enable identify/blink mode on node 04
 *   - :04MB1   put node 04 into config mode
 *   - :00MAD   put an unassigned node into config mode
 *   - :04NB2   assign new address 04 while node is in config mode
 *   - :FFWE3   broadcast WHO discovery
 *   - :FFCCF   broadcast close all local valves
 *   - :FFXE4   broadcast cancel config / identify mode
 *
 * Command letters:
 *   - P  ping, directed only, replies ACK
 *   - O  open local valve channel, directed only, arg = valve number
 *   - C  close local valve channel, directed, arg = valve number
 *   - C  broadcast close-all when sent as :FFC with no valve argument
 *   - S  status query, directed only, arg = valve number
 *   - V  firmware version query, directed only
 *   - I  identify mode, directed only
 *   - M  config mode entry, directed to current node or address 00
 *   - N  new address assignment while already in config mode
 *   - W  WHO discovery, broadcast only
 *   - X  cancel config / identify mode, broadcast only
 *
 * Example replies:
 *   - :04AKK       ACK from node 04
 *   - :04EKK       error from node 04
 *   - :04WKK       node 04 present
 *   - :04VvvvvKK   firmware version from node 04, vvvv is packed BCD
 *   - :04R1OKK     node 04 valve 1 open
 *   - :04R1CKK     node 04 valve 1 closed
 *   - :04R2OKK     node 04 valve 2 open
 *   - :04R2CKK     node 04 valve 2 closed
 *
 * Example version reply:
 *   - :04V0107KK   node 04 firmware version 1.07
 *
 * Checksum:
 *   8-bit sum of ASCII body bytes modulo 256.
 *   ':' and EOL are not included in the checksum.
 *
 * Behavioral notes:
 *   - Active-low status LED on PB0
 *   - RS-485 DE and /RE are tied together on PD2
 *   - Replies always include checksum
 *   - Requests require checksum by default
 *   - Checksumless requests are allowed only if REQUIRE_RX_CHECKSUM is disabled
 *   - Config/address commands require checksum if REQUIRE_CONFIG_CHECKSUM is enabled
 *   - Node address is stored in EEPROM and copied into RAM at boot
 *   - EEPROM identity uses one packed magic/address/inverse-address record
 *   - Fresh blank EEPROM is treated as unassigned, not corrupt
 *   - Corrupt EEPROM identity causes fast address-fault LED blink
 *   - Protocol is strict command/response, one request then one reply
 *   - Valve pulse width is 20 ms
 *   - Production valve output uses a 2.2 ohm series resistor
 *   - Watchdog is enabled to recover from firmware hangs during valve pulses
 *
 * Important limitation:
 *   The stored valve state is the last commanded state. This firmware does not
 *   sense actual valve position, water flow, or whether a solenoid is physically
 *   connected.
 *
 * Failure analysis note:
 *   The only firmware path that writes EEPROM is save_node_addr(), called from
 *   the N command while g_config_mode is true. With checksumless config enabled,
 *   a valid-looking :DDM followed by :DDN can enter config mode and rewrite the
 *   identity record. Hammering the bus increases exposure to malformed frames,
 *   collisions, or noise that can accidentally look like short commands.
 */

#define F_CPU 8000000UL

#include <avr/eeprom.h>
#include <avr/io.h>
#include <avr/wdt.h>
#include <stdbool.h>
#include <stdint.h>
#include <util/delay.h>

/* ============================================================================
 * BUILD CONFIGURATION
 * ========================================================================== */

/**
 * @brief Firmware version as packed 16-bit BCD.
 *
 * Example:
 *   0x0100 = 1.00
 *   0x0104 = 1.04
 *   0x0105 = 1.05
 *   0x0107 = 1.07
 *   0x0215 = 2.15
 */
#ifndef FW_VERSION
#define FW_VERSION 0x0107
#endif

/** @brief Default runtime address for an unassigned node. */
#define DEFAULT_NODE_ADDR              0x00

/** @brief EEPROM identity record magic byte. */
#define EEPROM_ADDR_MAGIC              0xA5u

/** @brief UART baud rate. */
#define BAUD                           9600UL

/** @brief UART divisor for F_CPU and BAUD. */
#define UBRR_VALUE                     ((F_CPU / (16UL * BAUD)) - 1UL)

/**
 * @brief Valve drive pulse width in milliseconds.
 *
 * Production valve output uses a 2.2 ohm series resistor with the latching
 * solenoid. The shorter pulse limits solenoid heating while still providing
 * enough energy to latch the valve.
 */
#define VALVE_PULSE_MS                 20

/** @brief RX-to-TX turnaround delay before transmitting reply. */
#define RS485_RX_TO_TX_TURNAROUND_MS   2

/** @brief Slot size for broadcast WHO reply staggering. */
#define WHO_SLOT_MS                    20

/** @brief Broadcast node address. */
#define NODE_BROADCAST_ADDR            0xFF

/** @brief Invalid / unassigned node address. */
#define NODE_INVALID_ADDR              0x00

/** @brief Maximum body length excluding ':' and EOL. */
#define RX_BODY_MAX_CHARS              8

/**
 * @brief Require checksums on all received request frames.
 *
 * Default production value is 1.
 *
 * Temporary compatibility setting while the current master still sends
 * checksumless requests:
 *
 *   -DREQUIRE_RX_CHECKSUM=0
 *
 * That allows normal old master traffic through while the master is updated.
 */
#ifndef REQUIRE_RX_CHECKSUM
#define REQUIRE_RX_CHECKSUM            1
#endif
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

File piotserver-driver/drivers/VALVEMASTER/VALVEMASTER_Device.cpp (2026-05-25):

#include "VALVEMASTER_Device.hpp"

#include "LogMgr.hpp"
#include "Utils.hpp"

#include <algorithm>
#include <cerrno>
#include <chrono>
#include <condition_variable>
#include <cctype>
#include <cstdlib>
#include <mutex>
#include <sstream>
#include <thread>

using namespace std;


// MARK: - Valve Master I2C Register Map

/**
 * @section valvemaster_i2c_register_map Valve Master I2C Register Map
 *
 * These values must match the register map implemented by valvenode_master.c
 * running on the ATmega88PB Valve Master board.
 *
 * The pIoTServer plugin talks only to the Valve Master over I2C. The Valve
 * Master then handles field-bus power, RS-485 direction control, and the slave
 * node command protocol.
 */

static constexpr uint8_t REG_COMMAND       = 0x00;
static constexpr uint8_t REG_STATUS        = 0x01;
static constexpr uint8_t REG_ARG0          = 0x02;
static constexpr uint8_t REG_ARG1          = 0x03;
static constexpr uint8_t REG_ARG2          = 0x04;
static constexpr uint8_t REG_RESULT        = 0x05;
static constexpr uint8_t REG_POWER_STATE   = 0x06;
static constexpr uint8_t REG_NODE_COUNT    = 0x07;
static constexpr uint8_t REG_REPLY_NODE    = 0x08;
static constexpr uint8_t REG_REPLY_CMD     = 0x09;
static constexpr uint8_t REG_REPLY_ARG0    = 0x0A;
static constexpr uint8_t REG_REPLY_ARG1    = 0x0B;
static constexpr uint8_t REG_VERSION_HI    = 0x10;
static constexpr uint8_t REG_VERSION_LO    = 0x11;
static constexpr uint8_t REG_NODE_MAP      = 0x20;


// MARK: - Valve Master Command Values

/**
 * @section valvemaster_command_values Valve Master Command Values
 *
 * These command bytes are written to REG_COMMAND.
 *
 * Command arguments must be written first. REG_COMMAND is written last.
 * The firmware executes the command from its main loop, not inside the TWI ISR.
 * The host then polls STATUS_BUSY and checks REG_RESULT.
 */

static constexpr uint8_t CMD_POWER_ON           = 0x01;
static constexpr uint8_t CMD_POWER_OFF          = 0x02;
static constexpr uint8_t CMD_WHO                = 0x03;
static constexpr uint8_t CMD_PING               = 0x04;
static constexpr uint8_t CMD_SET_CHANNEL        = 0x05;
static constexpr uint8_t CMD_GET_CHANNEL_STATUS = 0x06;
static constexpr uint8_t CMD_GET_NODE_VERSION   = 0x07;
static constexpr uint8_t CMD_CLOSE_ALL          = 0x0F;


// MARK: - Valve Master Status and Result Values

/**
 * @section valvemaster_status_result_values Valve Master Status and Result Values
 *
 * STATUS_BUSY means the Valve Master is still executing a command. The host
 * must not issue another command until STATUS_BUSY clears.
 *
 * STATUS_ERROR is tracked by firmware and mirrored through REG_RESULT.
 *
 * STATUS_POWER_ON reflects the Valve Master's current belief about switched
 * field-bus power.
 */

static constexpr uint8_t STATUS_BUSY     = (1u << 0);
static constexpr uint8_t STATUS_ERROR    = (1u << 1);
static constexpr uint8_t STATUS_POWER_ON = (1u << 2);

static constexpr uint8_t RESULT_OK       = 0x00;


// MARK: - Node Map and Timing Constants

/**
 * @section valvemaster_node_map_timing Node Map and Timing Constants
 *
 * NODE_MAP_BYTES is the maximum number of node entries exposed by the Valve
 * Master firmware.
 *
 * Timeouts here are host-side waits for the Valve Master BUSY bit to clear.
 * The Valve Master firmware has its own RS-485 timeouts internally.
 */

static constexpr uint8_t NODE_MAP_BYTES                 = 32;

static constexpr uint32_t WHO_SCAN_TIMEOUT_MS           = 10000;
static constexpr uint32_t PING_TIMEOUT_MS               = 2000;
static constexpr uint32_t VERSION_TIMEOUT_MS            = 2000;
static constexpr uint32_t SET_CHANNEL_TIMEOUT_MS        = 3000;
static constexpr uint32_t GET_CHANNEL_STATUS_TIMEOUT_MS = 3000;
static constexpr uint32_t CLOSE_ALL_TIMEOUT_MS          = 3000;
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

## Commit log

2026-05-03 Initial valvenode project import
    [valvenode-master.kicad_pcb, valvenode-master.kicad_sch, valvenode.kicad_pcb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]
2026-05-03 Add ValveNode design documentation
2026-05-10 Add close-all, RS-485 delay, and valve polarity fix
    [valvenode.c, valvenode_master.c]
2026-05-11 Update ValveNode master reliability and test tools
2026-05-18 Fix ValveNode EEPROM identity and test scripts
    [valvenode.c]
2026-05-22 Add VALVEMASTER piotserver driver and document valve node firmware
2026-05-23 Sync ValveNode master and slave firmware
2026-05-23 Fix ValveMaster diagnostics, harness checks, and slave EFUSE
    [VALVEMASTER_Device.cpp, plugin_harness.cpp]
2026-05-24 Add Valve Master action thread verification and harness tests
2026-05-25 Stabilize VALVEMASTER driver and test harness
    [VALVEMASTER_Device.cpp]
2026-06-08 Harden Valve Master I2C handling
2026-06-12 Add ValveNode RS-485 sniffer

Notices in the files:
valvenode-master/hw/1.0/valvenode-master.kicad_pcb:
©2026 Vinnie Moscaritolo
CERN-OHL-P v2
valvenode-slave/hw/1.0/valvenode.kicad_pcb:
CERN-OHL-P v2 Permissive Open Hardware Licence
